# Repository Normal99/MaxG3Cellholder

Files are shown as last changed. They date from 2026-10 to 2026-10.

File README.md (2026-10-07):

# MaxG3Cellholder

Cellholder for a custom 20s4p battery for the Segway Ninebot Max G3 without cutting the divider in the deck compartment.

* **Cells:** 80 × EVE INR21700-40P (Ø21.15 ±0.10 mm, 70.15 ±0.15 mm)
* **Configuration:** 20s4p, 72 V nominal / 84 V full
* **Envelope:** 141 × 270 mm footprint. Holder + cells are **71.8 mm** tall, which leaves ~9 mm of the 81 mm for copper, nickel, fish paper and heat shrink.
* **Placement:** the pack sits in front of the deck divider. The **BMS (ANT 24ZHE6-24S-220A) stands upright on the other side** of the divider, held by a dock that is **part of the top holder half**. Every lead and balance wire leaves the pack at the divider end.
* **Printed parts:** only what's needed. Just the two holder halves. The top one includes the BMS dock. No cover plates, no separate BMS holder.

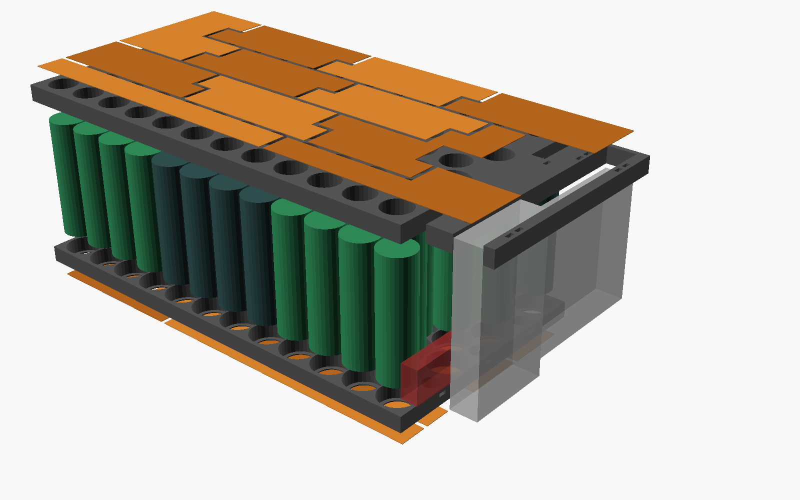
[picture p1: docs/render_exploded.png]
exploded view


---

## 1. What's in the repo

| Path | What it is |
|---|---|
| `stl/holder_bottom.stl`, `stl/holder_top.stl` | Cell holder halves, one piece each. Bottom is 270 mm long; top with BMS dock is 315 mm, so it needs a big bed. |
| `stl/holder_*_a.stl` / `_b.stl` | **The same halves split in two, for normal beds.** Every part fits a 256 × 256 bed (largest: `holder_top_a`, 214 × 141 mm, with the BMS dock). The two parts **lock together through 7 shared cell sockets** (§7). |
| `docs/copper_cutlist.svg` | **Copper cut list:** every distinct copper shape once, 1:1, with count, edge lengths and punch holes |
| `docs/copper_roll_plan.svg` | Every copper piece laid out on a **100 mm wide roll** |
| `docs/copper_top.svg`, `docs/copper_bottom.svg` | 1:1 position of every copper piece on each face, with punch holes, tab flaps and tongue fold lines |
| `docs/wiring_top.svg`, `docs/wiring_bottom.svg` | Wiring diagrams: group numbers, cell polarity, copper pieces and balance taps |
| `docs/layout.md` | Cut list table, plus every group, cell and copper piece |
| `scad/cellholder.scad` | Parametric OpenSCAD model: holder halves with BMS dock, tolerances, BMS size |
| `scad/layout_data.scad` | Generated layout data (do not edit by hand) |
| `generator/layout.py` | Generates the layout, copper pieces, diagrams and templates |

Coordinates used everywhere:

* **x** runs along the 270 mm length. **x = 0 is the divider end of the pack.**
* **y** runs across the 141 mm width. **y = 0 is the side wall the screw post's 80 mm is measured from.**
* **z** is up from the deck floor.

---

## 2. Layout and copper

top wiring
bottom wiring

The footprint fits a staggered grid of 7 rows (12/11/12/11/12/11/12) at 22.2 mm pitch. That makes **81 slots for 80 cells**. The spare slot is left empty at the divider end and doubles as a wire chase (§4).

Almost every 4p group is a compact **2 × 2 diamond**: 2 cells in one row and 2 in the next. The pack is built from bands of them:

| Rows (from the y = 0 side) | Groups | Direction |
|---|---|---|
| Rows 1–2 | **G1 → G5** (G1 = **B−**) | away from the divider |
| Far end | G6 | turn |
| Rows 3–4 | **G7 → G11** | back to the divider |
| Divider end | G12 | turn |
| Rows 5–6 | **G13 → G17** | away from the divider |
| Row 7 | **G18 → G20**, 4 cells in a line (G20 = **B+**) | back to the divider |

### Copper pieces: one straight bar per row

copper cut list

**Each copper piece is a straight bar along each row of cells it covers.**

* Where a piece covers two rows, the two bars are offset by half a cell (that's how the cells are staggered), giving a simple **step shape**.
* Every edge is a straight, square cut.
* **Every cell is fully covered.** Each piece only covers the cells of its own groups, so it is easy to see where it goes.

| Shape | Count | Size | What it is |
|---|---|---|---|
| **A** | **9** | 97.4 × 36 mm step: two 86.3 mm bars, offset 11.1 mm | Standard piece: two diamonds, 8 cells |
| **B** | 2 | same as A with one end squared off at the pack wall | |
| **C** | 2 | 175.5 × 16.7 mm strip | Row 7: 8 cells in a line |
| D–I | 1 each | step shapes | Turn pieces at the two ends of the pack |
| **B−**, **B+** | 1 each | with a **36 × 35 mm lead tongue** | Main leads (§5) |

**How to prepare the copper:**

* **Punch holes:** there's one 8 mm circle over every cell. Punch a hole there, lay the nickel strip over the copper, and weld the nickel to the cell through the hole and to the copper around it. Change `PUNCH_D` in `generator/layout.py` if your punch is a different size. The hole must be smaller than the cell's positive cap.
* **Cells are recessed 0.6 mm:** each cell stops against a thin lip 0.6 mm below the holder face. The copper lies flat on the holder, and the nickel only has to dip about 0.8 mm (lip + copper) through the hole to reach the cell.
* **Roll plan:** `docs/copper_roll_plan.svg` lays out every piece of both faces on a **100 mm wide roll**. One pack uses about **1.1 m of roll** per copper layer.
* **Gaps:** neighbouring pieces have a 2.5 mm gap. The generator checks that no copper ever comes within 10 mm of another group's cell centre.

**Other things to know about the layout:**

* **B− (G1)** and **B+ (G20)** both end at the divider end, on the **top** face.
* Copper pieces:
  * **Top face:** B0 (G1, main −), then B2, B4 … B18, then B20 (G20, main +). That's 11 pieces.
  * **Bottom face:** B1, B3 … B19. That's 10 pieces.
* The balance tap number equals the copper piece number. Taps B0–B20 go to BMS balance pins 0–20 (B0 = B−, B20 = B+).
* **Bands keep voltages low.** Neighbouring copper pieces are at most 12 groups apart (~50 V). Still lay fish paper over each face before wrapping.
* **The last row is the one compromise.** Seven rows can't be split into 2-row bands only. In row 7 the groups G18 → G19 → G20 sit end to end, so current flows lengthwise along the two C strips. **Use double-thickness copper (two layers) for the two C strips.**

To change the layout, edit `GROUP_PATTERN` in `generator/layout.py` and run it again (§10).

---

## 3. Stack-up (height budget 81 mm)

| Layer | mm |
|---|---|
| Fish paper / foam under the pack | your choice |
| Copper + nickel, bottom | ~0.4 |
| Cell recess (thin end-stop lip) | 0.6 |
| Cell (70.15 + 0.15 tolerance + fish-paper ring) | 70.6 |
| Cell recess, top | 0.6 |
| Copper + nickel, top | ~0.4 |
| **Total without wrap** | **~72.6** |

* **Holder halves:** each is 9.6 mm tall, with 9 mm deep sockets. Between the halves the cells are bare, over a 52.6 mm gap.
* **Bore:** Ø21.2 mm, picked with the fit test strip (§7): the cells press in firmly by hand. That leaves a 1.0 mm wall between neighbouring cells. On a different printer, print the test strip again and set `cell_bore` in **both** `scad/cellholder.scad` and `generator/layout.py`.
* **Welding window:** Ø17 mm, the opening in the end stop over every cell.

---

## 4. Deck features

### Divider (20 mm tall, 10 mm wide, full width)

The pack's x = 0 face sits against the divider. Nothing passes under or through the divider, so the 0.5 mm indent under it doesn't matter. Everything that goes to the BMS leaves the pack **above z = 20 mm** at the divider end and goes over the divider:

* **Top balance wires** run over the top face, under the fish paper, to the divider end.
* **Bottom balance wires** run under the bottom face to the **wire chase**: the empty cell slot at the divider end, open top to bottom. The wires rise inside it and leave sideways through the open gap between the holder halves, above the divider.
* **Main leads:** see §5.

### Screw post (80 mm from the side wall, 10 mm tall, just in front of the divider)

The post is on the **BMS side** of the divider (`post_side = "bms"`), so the BMS simply stands just behind it (§8).

* If it turns out to be on the **pack side**, set `post_side = "pack"`. The bottom holder half then gets a Ø12 × 11 mm pocket, and the empty cell slot is placed right over the post.
* If the 80 mm is measured from the **other** side wall, set `POST_FROM_SIDE = 141 - 80` (= 61) in `generator/layout.py`. The whole pattern mirrors automatically.

**Measure before you print:**

* post diameter (assumed Ø10)
* distance from the divider (assumed centre 6 mm)
* which side wall the 80 mm is measured from

---

## 5. Main leads (B−, B+): solder first, then weld

You can't solder to the copper once it's welded: the copper soaks up the heat and cooks the cells. So the leads go onto **tongues that stick out past the end of the pack**, and you solder them on the bench before any cell is touched.

1. Cut the **B−** and **B+** pieces from the cut list **with the tongue**. Each tongue is 36 mm wide and runs **35 mm** past the x = 0 edge (dashed fold line on the template). A doubled tongue (two layers of copper) makes the joint even stronger.
2. **On the bench, with no cells near it:** tin the tongue and solder the lead (10 or 12 AWG silicone) along the outer ~20 mm. A 100 W+ iron or a small torch makes copper easy. Let it cool and slide heat shrink over the joint.
3. Pre-bend the tongue 90° **downwards** at the x = 0 edge.
4. Lay the piece on its cells, add the nickel and weld. The joint hangs down the divider-end face of the top holder half, **above the divider**.
5. **Strain relief:** each tongue folds down through a notch in the BMS dock arm. Zip-tie the lead through the hole pair beside the notch, or through the tie slot in the end wall behind it (y = 32 for B−, y = 109 for B+). That way the lead's weight pulls on the plastic, not on the welds.

**No-solder alternative:** crimp a ring lug on the lead and bolt it to the tongue with M5 or M6 (spring washer + nyloc), outside the pack.

## 6. Balance tabs

There is one tab per copper piece, at the small rectangle on the templates. It sits over plastic between the cells, never over a cell terminal.

1. On each copper piece, cut a **5 × 7 mm U-flap** at the marked spot.
2. **Solder the balance wire (22–24 AWG silicone) to the flap on the bench**, before welding. Then weld the piece. Solder the B0 and B20 balance wires to the main-lead tongues in the same bench step.
3. Run the wires to the divider end:
   * **Top face:** lay the wires flat on the top face.
   * **Bottom face:** lay them flat on the bottom face and route them up through the wire chase.
4. Fix them with kapton tape, then cover each face with fish paper.
5. Put a fuse or PTC on each balance lead at the connector end if your BMS harness doesn't already have them.

---

## 7. Printing

### What to print

It's only the two holder halves. The BMS dock is part of the top half.

| Your bed | Print these |
|---|---|
| **≥ 315 × 141 mm** | `holder_bottom.stl` + `holder_top.stl` (one piece each) |
| **Smaller, e.g. 256 × 256 mm** (Bambu, Prusa, Ender …) | the four split parts below |

The split parts are all 9.6 mm tall:

| File | Size (mm) |
|---|---|
| `stl/holder_bottom_a.stl` | 146 × 141 |
| `stl/holder_bottom_b.stl` | 157 × 141 |
| `stl/holder_top_b.stl` | 135 × 141 |
| `stl/holder_top_a.stl` (has the BMS dock) | 214 × 141 |

### Print order

0. **`stl/bore_test.stl` first: the cell fit test** (137 × 35 mm, ~15 cm³, about half an hour).
   * It's a row of 6 cell holes, **21.1 to 21.6 mm**, built exactly like the holder: same lip, depth, spacing and circle resolution. Each hole has its size printed on the tab next to it.
   * Push a cell into each hole and pick the one where it goes in **firmly by hand and doesn't fall out** when you turn the strip over.
   * Set that number as `cell_bore` in `scad/cellholder.scad` **and** `BORE_D` in `generator/layout.py`, then re-run `python3 generator/layout.py` and `sh scad/export.sh`. (Or just tell Claude the number.)

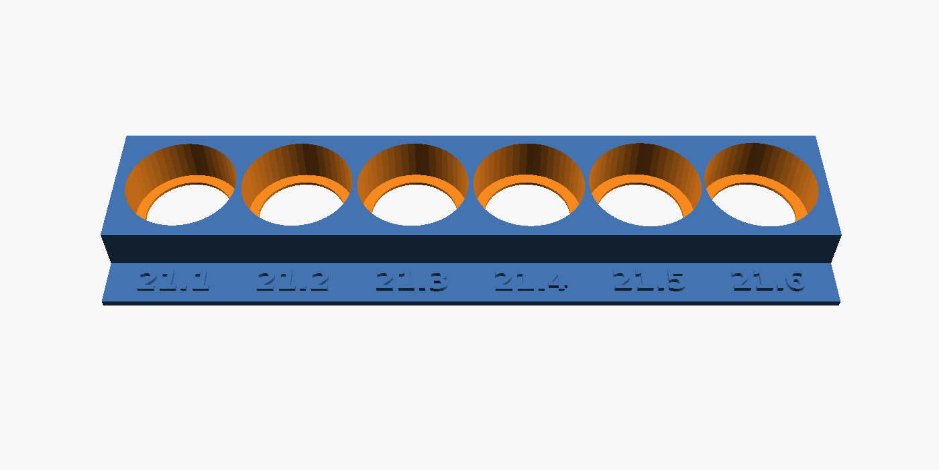
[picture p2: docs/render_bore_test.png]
fit test strip
   
1. `holder_bottom_a`. Check a few cells in it before printing the rest.
2. `holder_bottom_b`. It locks to `_a` through the key cells (see below).
3. `holder_top_b`.
4. **`holder_top_a` last.** It places the BMS slot, so check these first (§4, §8):
   * the screw-post position
   * at least ~91 mm of height past the divider

### Settings

* **Material: PETG, ASA or ABS. Not PLA** (it creeps and softens in a hot deck).
* 0.2 mm layers (the 0.6 mm lip under each cell is then exactly 3 layers), 3 walls, 15–25 % infill.
* **Orientation:** as exported, flat face down. **No supports** for any part. The BMS dock is a flat arm in the same layer as the top half, with only vertical holes.
* **Split parts:** they join mechanically, so no glue or pins are needed (see below).

### How the split parts lock together

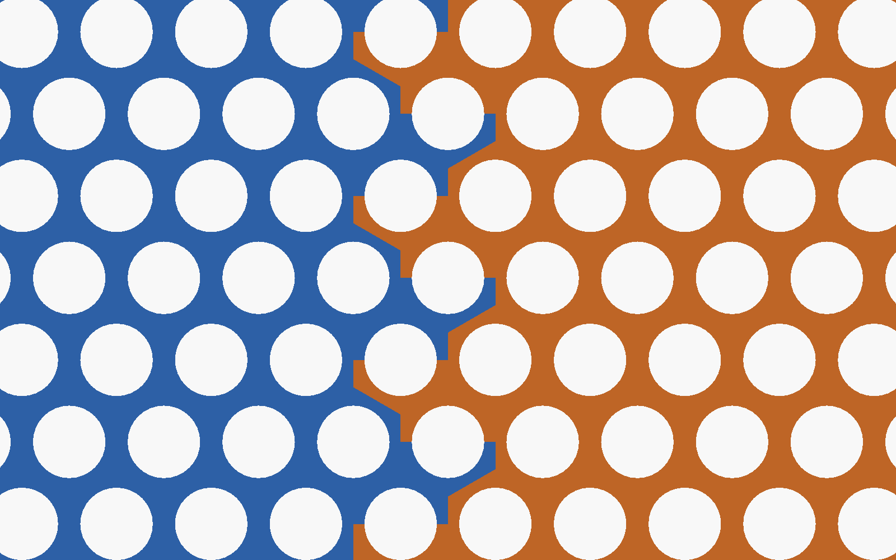
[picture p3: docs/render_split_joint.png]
split joint


The seam doesn't run between cells. It runs **through a column of cells**, one **key cell** per row (7 per half). In the bottom half they're at x ≈ 124 / 135 mm, in the top half one column further, at x ≈ 146 / 157 mm.

* **How a key cell is split:** its socket is cut in half across the centre. One half belongs to part `_a`, the other to `_b`.
* **Alternating halves:** row by row, `_a` gets the upper half, then the lower half, and so on.
* **Why it locks:** once a key cell is pushed in, it sits in a half-socket of **both** parts. Each key cell acts as a 21 mm dowel, and because the halves alternate, the parts can't slide apart in any direction across the pack.
* **Assembly:** lay `_a` and `_b` side by side on the table, close the seam, and **push the 7 key cells in first**. After that, fill the rest.
* **Offset seams:** the top and bottom seams are a column apart, so they never line up. Each seam is backed by a solid stretch of the other half, like staggered joints in brickwork, and the pack has no weak line to fold along.
* **Extra security:** a drop of CA glue along the seam keeps the parts together while you handle them without cells. The welded copper and nickel, which bridge the seam on both faces, make the joint permanent.

## 8. BMS dock (built into the top holder half)

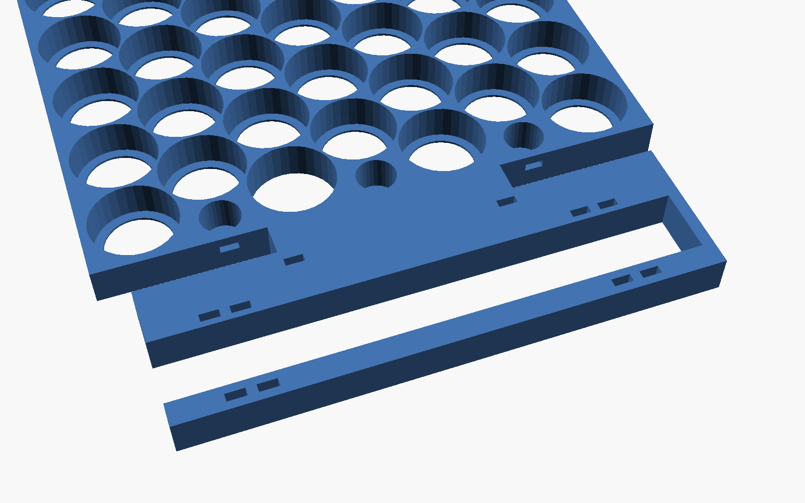
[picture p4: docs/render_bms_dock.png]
BMS dock


The ANT BMS (125 × 90 × 16 mm) **stands upright on its long edge** on the deck floor, parallel to the divider, just behind the screw post. The **top holder half** has a flat arm that reaches over the divider (it sits at 62–72 mm height, the divider is only 20 mm tall) with a **slot the BMS drops into**. It only takes about **45 mm of deck length** past the divider, and there is no separate part to print or fix down.

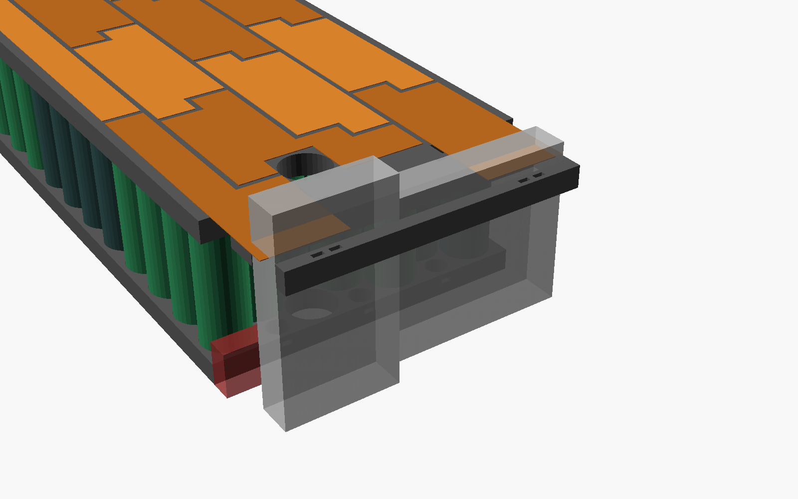
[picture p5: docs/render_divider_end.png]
divider end


* **Height:** the BMS is 90 mm tall standing, so make sure the space past the divider has at least ~91 mm.
* **Connector end** (wide 90 mm head): the slot is **open** there, so the balance connectors stay free.
* **Narrow end** (70 mm section with the power leads): a cross bar closes the slot. That section sits 10 mm off the floor, so the lower leads have room to bend outwards.
* **Hold-down:** two zip ties, one near each end, through the hole pairs in both rails and over the BMS's top edge.
* **Lead notches:** the arm has notches at the pack end, so the **B− / B+ tongues still fold down** over the end of the pack. A hole pair beside each notch takes a zip tie around the lead (strain relief).
* **Printing:** the arm is the same 9.6 mm slab as the half, so it prints flat with it.

Settings in `scad/cellholder.scad`:

* `bms_head_at`: which side of the deck the connector end faces (`"y0"` or `"y1"`)
* `bms_y`: where the BMS sits across the deck
* `bms_*` sizes, if you change BMS
* `bms_dock = false` removes the dock

Then run `sh scad/export.sh`.

## 9. Assembly order

1. Insert the cells into the **bottom** half, following `docs/wiring_bottom.svg`. With the split parts, put the 7 key cells in first to lock `_a` and `_b` together (§7). Then fit the **top** half the same way.
   * **Top** terminals: G1 is **−** up, G2 is **+** up, and so on, alternating.
   * Before you weld anything, check every cell's polarity against the diagrams with a meter.
2. Fit fish-paper rings on the positive ends.
3. **Bottom face:**
   * Pre-solder the balance wires to the flaps of B1 … B19.
   * Lay the punched copper pieces (see `docs/copper_bottom.svg`; it's drawn as seen from below).
   * Weld the nickel through the holes.
   * Tape the wires and route them into the chase.
4. **Top face:**
   * Pre-solder the B− and B+ leads and the B2 … B18 balance wires.
   * Lay the copper, weld the nickel, fold the tongues down and zip-tie the leads.
5. Measure each tap against B0 before plugging into the BMS. Each step should be ~3.6–4.2 V.
6. Fish paper over both faces, then wrap the pack (foam + heat shrink). Make sure the controller is rated for **84 V** before connecting.

---

## 10. Regenerating / customising

```sh
pip install shapely                 # one time
python3 generator/layout.py         # layout -> scad/layout_data.scad + docs/*.svg + docs/layout.md
sh scad/export.sh                   # all STLs into stl/ (OpenSCAD 2021.01+)
openscad scad/cellholder.scad       # preview, set part = "assembly" / "exploded"
```

Parameters live in two places:

* **`generator/layout.py`:**
  * envelope (`PACK_L`, `PACK_W`) and `PITCH`
  * the screw post (`POST_FROM_SIDE`, `POST_FROM_DIVIDER`, `POST_D`, `POST_H`)
  * copper gap, punch hole size (`PUNCH_D`), lead tongue size (`LEAD_W`, `LEAD_LEN`) and roll width (`ROLL_W`)
  * the group pattern (`GROUP_PATTERN`)
* **`scad/cellholder.scad`:**
  * cell size and bore, welding window, cell recess, socket depth, tie slots
  * screw post side (`post_side`)
  * BMS size and dock settings

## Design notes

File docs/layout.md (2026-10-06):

# Generated layout

Generated by `generator/layout.py`. Coordinates in mm, x = 0 at the divider, y = 0 at the side wall the screw post is measured from.

## Copper cut list

Every copper edge is a straight line. Identical letters = identical pieces (a mirrored copy is the same template flipped over).

| Shape | Count | Pieces |
|---|---|---|
| A | 9 | top B2, top B4, top B8, top B10, top B14, bottom B3, bottom B9, bottom B13, bottom B15 |
| B | 2 | top B16, bottom B1 |
| C | 2 | top B18, bottom B19 |
| D | 1 | top B6 |
| E | 1 | top B12 |
| F | 1 | bottom B5 |
| G | 1 | bottom B7 |
| H | 1 | bottom B11 |
| I | 1 | bottom B17 |
| B- | 1 | top B0 + 36 x 35 mm lead tongue |
| B+ | 1 | top B20 + 36 x 35 mm lead tongue |

All pieces fit across a 100 mm copper roll; one pack uses about 1091 mm of roll per copper layer (see copper_roll_plan.svg).

Largest voltage step between neighbouring copper pieces on one face: 12 groups (~50 V at full charge).

## Series groups

| Group | Top terminal | Cells (x, y) | Contacts to next group |
|---|---|---|---|
| G1 | - | (13, 13), (24, 32), (35, 13), (46, 32) | 3 |
| G2 | + | (57, 13), (68, 32), (80, 13), (91, 32) | 3 |
| G3 | - | (102, 13), (113, 32), (124, 13), (135, 32) | 3 |
| G4 | + | (146, 13), (157, 32), (168, 13), (179, 32) | 3 |
| G5 | - | (190, 13), (202, 32), (213, 13), (224, 32) | 3 |
| G6 | + | (235, 13), (246, 32), (257, 13), (257, 51) | 3 |
| G7 | - | (213, 51), (224, 70), (235, 51), (246, 70) | 3 |
| G8 | + | (168, 51), (179, 70), (190, 51), (202, 70) | 3 |
| G9 | - | (124, 51), (135, 70), (146, 51), (157, 70) | 3 |
| G10 | + | (80, 51), (91, 70), (102, 51), (113, 70) | 3 |
| G11 | - | (35, 51), (46, 70), (57, 51), (68, 70) | 4 |
| G12 | + | (13, 51), (24, 70), (24, 109), (35, 90) | 3 |
| G13 | - | (46, 109), (57, 90), (68, 109), (80, 90) | 3 |
| G14 | + | (91, 109), (102, 90), (113, 109), (124, 90) | 3 |
| G15 | - | (135, 109), (146, 90), (157, 109), (168, 90) | 3 |
| G16 | + | (179, 109), (190, 90), (202, 109), (213, 90) | 3 |
| G17 | - | (224, 109), (235, 90), (246, 109), (257, 90) | 4 |
| G18 | + | (190, 128), (213, 128), (235, 128), (257, 128) | 1 |
| G19 | - | (102, 128), (124, 128), (146, 128), (168, 128) | 1 |
| G20 | + | (13, 128), (35, 128), (57, 128), (80, 128) | - |

## Copper pieces

| Face | Tap | Shape | Joins | Tab / lead position (x, y) |
|---|---|---|---|---|
| top | B0 | B- | G1 | lead tongue 36 mm wide at y = 22.4 |
| top | B2 | A | G2 + G3 | (68.4, 19.2) |
| top | B4 | A | G4 + G5 | (157.2, 19.2) |
| top | B6 | D | G6 + G7 | (223.8, 57.7) |
| top | B8 | A | G8 + G9 | (135.0, 57.7) |
| top | B10 | A | G10 + G11 | (46.2, 57.7) |
| top | B12 | E | G12 + G13 | (35.1, 102.5) |
| top | B14 | A | G14 + G15 | (101.7, 102.5) |
| top | B16 | B | G16 + G17 | (190.5, 102.5) |
| top | B18 | C | G18 + G19 | (112.8, 128.2) |
| top | B20 | B+ | G20 | lead tongue 36 mm wide at y = 118.6 |
| bottom | B1 | B | G1 + G2 | (35.1, 32.0) |
| bottom | B3 | A | G3 + G4 | (112.8, 19.2) |
| bottom | B5 | F | G5 + G6 | (201.6, 19.2) |
| bottom | B7 | G | G7 + G8 | (179.4, 57.7) |
| bottom | B9 | A | G9 + G10 | (90.6, 57.7) |
| bottom | B11 | H | G11 + G12 | (35.1, 76.9) |
| bottom | B13 | A | G13 + G14 | (57.3, 102.5) |
| bottom | B15 | A | G15 + G16 | (146.1, 102.5) |
| bottom | B17 | I | G17 + G18 | (201.6, 128.2) |
| bottom | B19 | C | G19 + G20 | (24.0, 128.2) |

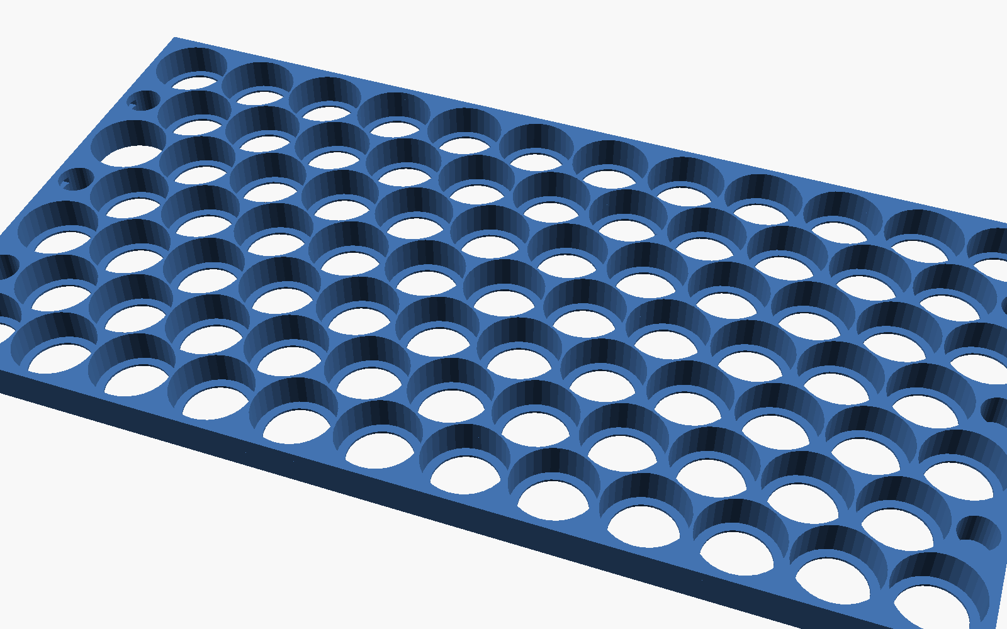
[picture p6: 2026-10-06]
docs/render_holder_bottom.png

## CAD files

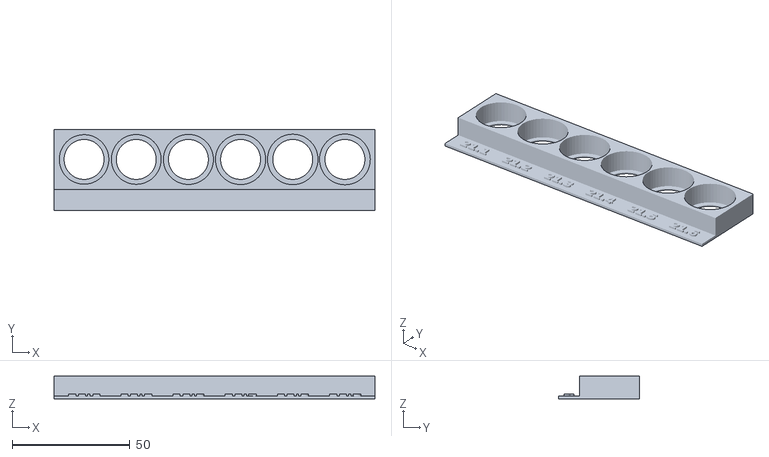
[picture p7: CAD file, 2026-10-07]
stl/bore_test.stl
136.6 x 34.6 x 9.60

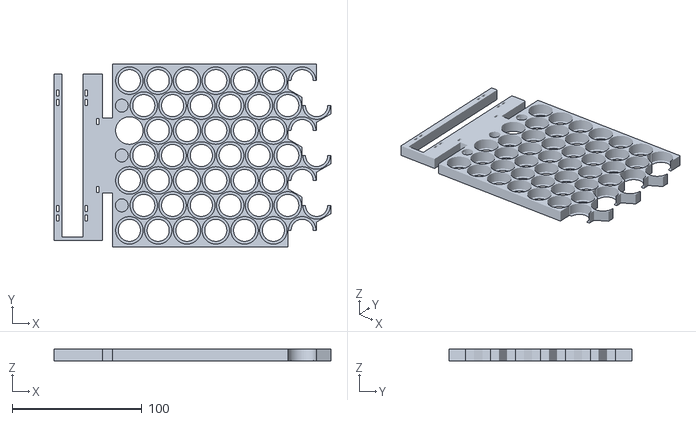
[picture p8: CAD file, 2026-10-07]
stl/holder_top_a.stl
213.5 x 141.0 x 9.60

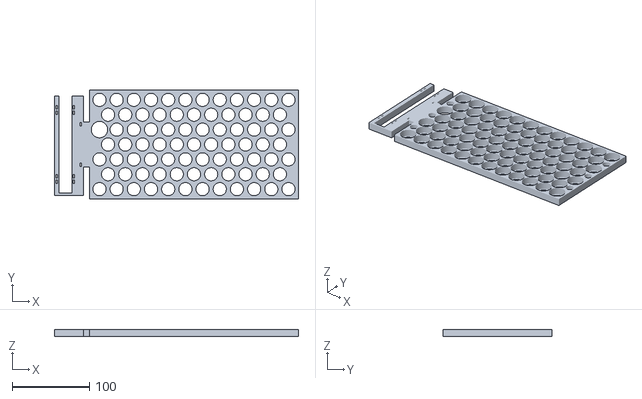
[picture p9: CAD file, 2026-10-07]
stl/holder_top.stl
315.2 x 141.0 x 9.60

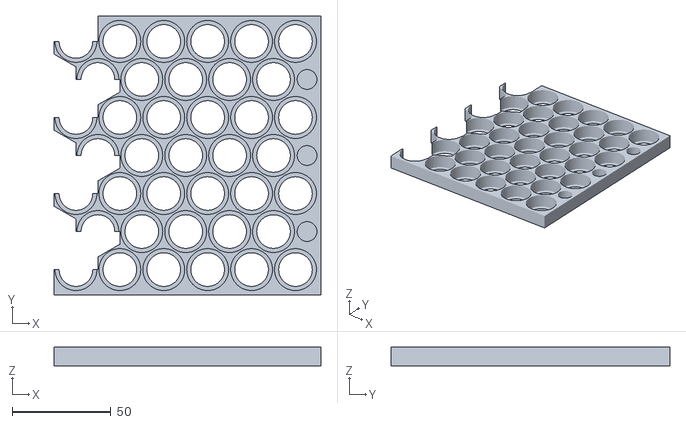
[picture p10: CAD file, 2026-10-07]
stl/holder_top_b.stl
135.0 x 141.0 x 9.60

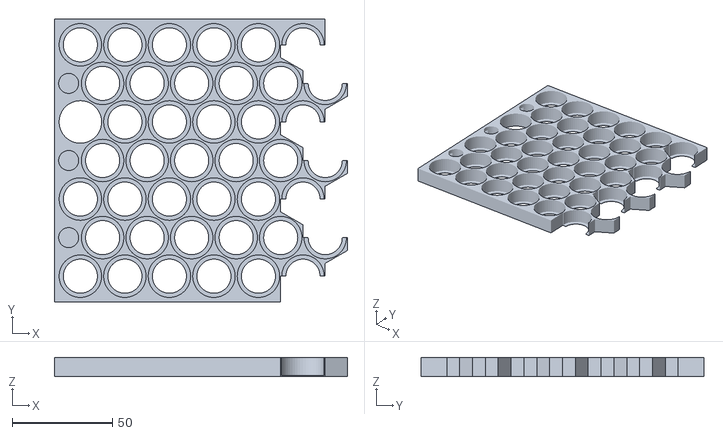
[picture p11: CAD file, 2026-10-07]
stl/holder_bottom_a.stl
146.1 x 141.0 x 9.60

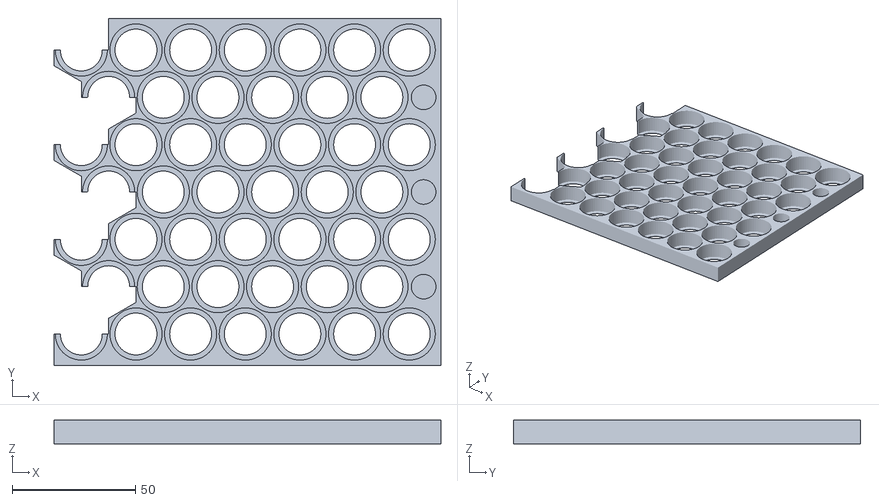
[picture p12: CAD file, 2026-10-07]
stl/holder_bottom_b.stl
157.2 x 141.0 x 9.60

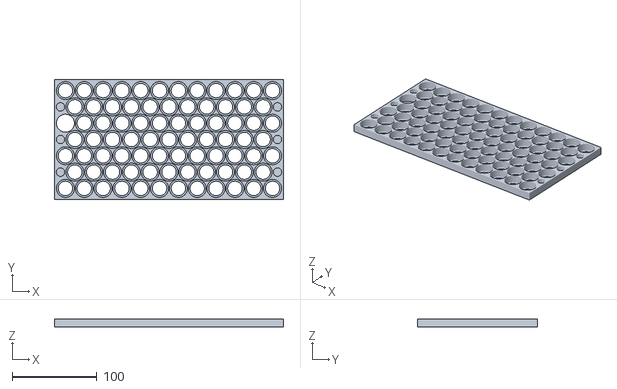
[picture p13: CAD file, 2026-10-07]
stl/holder_bottom.stl
270.0 x 141.0 x 9.60

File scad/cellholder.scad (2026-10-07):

// =====================================================================
//  Segway Ninebot Max G3 - 20s4p 21700 cell holder (EVE 40P) + BMS dock
//  Pack envelope 141 x 270 x 81 mm, fits in front of the deck divider,
//  the BMS stands upright on the other side of the divider, held by an
//  arm that is part of the TOP holder half and reaches over the divider.
//
//  Cell layout and copper pieces come from layout_data.scad, generated by
//  ../generator/layout.py.
//
//  Coordinates: x = 270 mm length, x = 0 is the DIVIDER end of the pack
//               (the divider is x = -div_w .. 0, the BMS is at x < -div_w)
//               y = 141 mm width,  y = 0 is the side wall the screw post
//                                   is measured from (80 mm)
//               z = height,         z = 0 is the deck floor
//
//  Parts (set `part`, or run export.sh):
//    holder_bottom, holder_top             cell holder halves (the top one carries the BMS dock)
//    holder_bottom_a/_b, holder_top_a/_b   same, split for beds < 270 mm
//    assembly                              everything in place (preview only)
// =====================================================================
include <layout_data.scad>

part = "assembly";

/* [Cell] */
cell_d      = 21.15;  // EVE 40P datasheet: 21.15 +-0.10
cell_len    = 70.6;   // 70.15 +0.15 max + fish-paper ring + margin
cell_bore   = 21.2;   // socket bore, picked with the fit test strip (1.0 mm web at 22.2 pitch). Also in layout.py
window_d    = 17.0;   // opening in the end stop over every cell. Also in layout.py

/* [Holder] */
cell_recess = 0.6;    // cells sit this far below the holder face (= end-stop lip, 3 layers)
sock        = 9.0;    // socket depth per half
void_d      = 10.0;   // lightening pocket in the empty end spots of the short rows
tie_w       = 4.6;    // zip-tie slot through the end wall (fits 3.6 mm ties)
tie_h       = 2.0;

/* [Screw post] */
post_clear  = 1.0;    // radial clearance
post_extra  = 1.0;    // height clearance

/* [Deck] */
div_w       = 10.0;   // divider width (x)
div_h       = 20.0;   // divider height
post_side   = "bms";  // "bms": post is on the BMS side of the divider, "pack": on the cell side

/* [BMS dock - ANT BMS 24ZHE6-24S-220A, built into the TOP holder half] */
bms_dock    = true;
bms_l       = 125;    // BMS length
bms_w       = 90;     // BMS width at the connector (head) end = height when standing
bms_body_w  = 70;     // width of the narrow section the power leads come out of
bms_head_l  = 50;     // length of the wide head section (balance connectors on its end)
bms_t       = 16;     // BMS thickness
bms_y       = 70.5;   // centre of the BMS across the deck (y)
bms_head_at = "y1";   // which deck side the connector end faces: "y0" or "y1"
bms_slot    = 0.4;    // clearance in the slot (thickness and length)
dock_rail   = 6;      // width of the outer rail of the slot
dock_end    = 3;      // cross bar that closes the slot at the narrow end
lead_notch  = 8;      // notches at the pack end the B-/B+ tongues fold down through

/* [Fit test strip] */
test_bores  = [21.1, 21.2, 21.3, 21.4, 21.5, 21.6];   // hole sizes to try

/* [Quality] */
$fn = 48;

// ---------------------------------------------------------------------
L = pack_l;
W = pack_w;
half_h   = cell_recess + sock;
total_h  = cell_len + 2 * cell_recess;
gap_h    = cell_len - 2 * sock;
post_d   = post[2];
post_h   = post[3];
// screw post position: measured from the divider face on its own side
post_xy  = post_side == "pack" ? [post[0], post[1]] : [-div_w - post[0], post[1]];
tie_z    = half_h - 2.5 - tie_h;   // tie slot (local z)
// BMS dock: the BMS stands on the floor just behind the screw post
bms_xn   = post_side == "bms" ? post_xy[0] - post_d / 2 - post_clear - 1 : -div_w - 1;   // near face
bms_xf   = bms_xn - bms_t;                                                              // far face
bms_y0   = bms_y - bms_l / 2;
bms_y1   = bms_y + bms_l / 2;
narrow_y1 = bms_head_at == "y0";   // the narrow end (closed by the cross bar) is at y1
echo(str("PACK HEIGHT = ", total_h, " mm + copper/nickel/insulation (limit 81)  gap between halves = ", gap_h));
assert(total_h <= 78, "pack too tall for 81 mm with copper and insulation");

// ---------------------------------------------------------------------
// 2D helpers
// ---------------------------------------------------------------------
module outline() { square([L, W]); }

module split_mask(which, face = "bottom") {
    // which: "all", "a", "b"   (zig-zag split between cells)
    // (the BMS dock at x < 0 belongs to part "a")
    sa = face == "top" ? split_a_top : split_a;   // the two halves split at different columns
    if (which == "a") union() { polygon(sa); translate([-200, -1]) square([200.01, W + 2]); }
    else if (which == "b") difference() { translate([0, -1]) square([L + 1, W + 2]); polygon(sa); }
    else translate([-200, -1]) square([L + 201, W + 2]);
}

module bores()   { for (c = cells) translate([c[0], c[1]]) circle(d = cell_bore); }
module windows() { for (c = cells) translate([c[0], c[1]]) circle(d = window_d); }
module chase2d() { translate(chase) circle(d = cell_bore); }
module post2d()  {   // open towards the divider end so it never grazes the wall
    hull() for (dx = [0, -post_xy[0] - 1]) translate(post_xy + [dx, 0]) circle(d = post_d + 2 * post_clear);
}
module voids()   { for (v = concat(voids_x0, voids_x1)) translate(v) circle(d = void_d); }
function in_notch(y) = len([for (l = leads) if (abs(y - l[0]) < l[2] / 2) 1]) > 0;
module tie_slots(face) {
    // lead strain-relief slots through the end wall; on the top half with
    // the dock only those that open into a lead notch stay
    for (v = voids_x0) if (!(face == "top" && bms_dock) || in_notch(v[1]))
        translate([-1, v[1] - tie_w / 2]) square([v[0], tie_w]);
}

// BMS dock outline (world xy, x < 0): solid bridge over the divider up to
// the slot, outer rail beyond it, cross bar at the narrow end, notches for
// the lead tongues, zip-tie hole pairs for the BMS straps and the leads.
module dock2d() {
    s  = bms_slot / 2;
    yl = narrow_y1 ? bms_y0 - s : bms_y0 - s - dock_end;
    yh = narrow_y1 ? bms_y1 + s + dock_end : bms_y1 + s;
    xr = bms_xf - s - dock_rail;                  // outer edge of the rail
    module pair(x, y, along_x = false) {          // two tie holes 7 mm apart
        for (d = [-3.5, 3.5])
            translate(along_x ? [x + d, y] : [x, y + d])
                square(along_x ? [tie_h, tie_w] : [tie_h, tie_w], center = true);
    }
    difference() {
        union() {
            translate([bms_xn + s, yl]) square([-bms_xn - s + 0.01, yh - yl]);   // bridge
            translate([xr, yl]) square([dock_rail, yh - yl]);                    // outer rail
            translate([xr, narrow_y1 ? bms_y1 + s : yl]) square([bms_xn + s - xr, dock_end]);
        }
        for (l = leads) translate([-lead_notch, l[0] - l[2] / 2 - 1]) square([lead_notch + 1, l[2] + 2]);
        // BMS straps: hole pairs in both rails near each end of the BMS
        for (y = [bms_y0 + 18, bms_y1 - 18]) {
            pair(bms_xn + s + 2.5, y);
            pair(xr + dock_rail / 2, y);
        }
        // lead straps: hole pair beside each notch
        for (l = leads) for (d = [-1, 1])
            translate([-lead_notch - 3.5, l[0] + d * (l[2] / 2 + 4)]) square([tie_h, tie_w], center = true);
    }
}

// 3D slab: linear_extrude a 2D region between z0 and z1
module slab(z0, z1) { translate([0, 0, z0]) linear_extrude(z1 - z0) children(); }

// ---------------------------------------------------------------------
// Holder half. Local coords: z = 0 is the outer face (copper side),
// xy = world xy. Print in this orientation (face down, no supports).
// The cells stop against a thin lip, cell_recess below the face, so the
// punched copper + nickel only has to dip cell_recess to reach the cell.
// ---------------------------------------------------------------------
module holder_half(face = "bottom", which = "all") {
    zs = cell_recess;             // sockets start
    zt = half_h;                  // inner end
    pocket = face == "bottom" && post_side == "pack";
    zp = pocket ? min(zt, post_h + post_extra) : -1;

    module socket_layer(cut_post, cut_tie) {
        intersection() {
            split_mask(which, face);
            difference() {
                outline();
                bores();
                chase2d();
                voids();
                if (cut_post) post2d();
                if (cut_tie) tie_slots(face);
            }
        }
    }
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

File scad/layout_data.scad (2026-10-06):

// GENERATED by generator/layout.py - do not edit by hand

pack_l = 270.0;
pack_w = 141.0;
pitch = 22.2;
// [x, y, group(1-based), up-terminal]
cells = [[12.900,12.823,1,"-"],[35.100,12.823,1,"-"],[57.300,12.823,2,"+"],[79.500,12.823,2,"+"],[101.700,12.823,3,"-"],[123.900,12.823,3,"-"],[146.100,12.823,4,"+"],[168.300,12.823,4,"+"],[190.500,12.823,5,"-"],[212.700,12.823,5,"-"],[234.900,12.823,6,"+"],[257.100,12.823,6,"+"],[24.000,32.048,1,"-"],[46.200,32.048,1,"-"],[68.400,32.048,2,"+"],[90.600,32.048,2,"+"],[112.800,32.048,3,"-"],[135.000,32.048,3,"-"],[157.200,32.048,4,"+"],[179.400,32.048,4,"+"],[201.600,32.048,5,"-"],[223.800,32.048,5,"-"],[246.000,32.048,6,"+"],[12.900,51.274,12,"+"],[35.100,51.274,11,"-"],[57.300,51.274,11,"-"],[79.500,51.274,10,"+"],[101.700,51.274,10,"+"],[123.900,51.274,9,"-"],[146.100,51.274,9,"-"],[168.300,51.274,8,"+"],[190.500,51.274,8,"+"],[212.700,51.274,7,"-"],[234.900,51.274,7,"-"],[257.100,51.274,6,"+"],[24.000,70.500,12,"+"],[46.200,70.500,11,"-"],[68.400,70.500,11,"-"],[90.600,70.500,10,"+"],[112.800,70.500,10,"+"],[135.000,70.500,9,"-"],[157.200,70.500,9,"-"],[179.400,70.500,8,"+"],[201.600,70.500,8,"+"],[223.800,70.500,7,"-"],[246.000,70.500,7,"-"],[35.100,89.726,12,"+"],[57.300,89.726,13,"-"],[79.500,89.726,13,"-"],[101.700,89.726,14,"+"],[123.900,89.726,14,"+"],[146.100,89.726,15,"-"],[168.300,89.726,15,"-"],[190.500,89.726,16,"+"],[212.700,89.726,16,"+"],[234.900,89.726,17,"-"],[257.100,89.726,17,"-"],[24.000,108.952,12,"+"],[46.200,108.952,13,"-"],[68.400,108.952,13,"-"],[90.600,108.952,14,"+"],[112.800,108.952,14,"+"],[135.000,108.952,15,"-"],[157.200,108.952,15,"-"],[179.400,108.952,16,"+"],[201.600,108.952,16,"+"],[223.800,108.952,17,"-"],[246.000,108.952,17,"-"],[12.900,128.177,20,"+"],[35.100,128.177,20,"+"],[57.300,128.177,20,"+"],[79.500,128.177,20,"+"],[101.700,128.177,19,"-"],[123.900,128.177,19,"-"],[146.100,128.177,19,"-"],[168.300,128.177,19,"-"],[190.500,128.177,18,"+"],[212.700,128.177,18,"+"],[234.900,128.177,18,"+"],[257.100,128.177,18,"+"]];
chase = [12.900,89.726];
post = [6.000,80.000,10.000,10.000];
// [y, name, width]  main lead tongues leave over the divider end (x = 0)
leads = [[22.436,"B-",35.952],[118.564,"B+",35.952]];
voids_x0 = [[7.050,32.048],[7.050,70.500],[7.050,108.952]];
voids_x1 = [[262.950,32.048],[262.950,70.500],[262.950,108.952]];
split_a = [[0.000,141.000],[135.000,141.000],[135.000,128.177],[112.800,128.177],[112.800,121.769],[123.900,115.360],[123.900,108.952],[146.100,108.952],[146.100,102.543],[135.000,96.134],[135.000,89.726],[112.800,89.726],[112.800,83.317],[123.900,76.909],[123.900,70.500],[146.100,70.500],[146.100,64.091],[135.000,57.683],[135.000,51.274],[112.800,51.274],[112.800,44.866],[123.900,38.457],[123.900,32.048],[146.100,32.048],[146.100,25.640],[135.000,19.231],[135.000,12.823],[112.800,12.823],[112.800,0.000],[0.000,0.000]];          // bottom half
split_a_top = [[0.000,141.000],[157.200,141.000],[157.200,128.177],[135.000,128.177],[135.000,121.769],[146.100,115.360],[146.100,108.952],[168.300,108.952],[168.300,102.543],[157.200,96.134],[157.200,89.726],[135.000,89.726],[135.000,83.317],[146.100,76.909],[146.100,70.500],[168.300,70.500],[168.300,64.091],[157.200,57.683],[157.200,51.274],[135.000,51.274],[135.000,44.866],[146.100,38.457],[146.100,32.048],[168.300,32.048],[168.300,25.640],[157.200,19.231],[157.200,12.823],[135.000,12.823],[135.000,0.000],[0.000,0.000]];  // top half
// key cells of the print splits (socket shared by both parts)
split_keys = [[123.900,12.823],[135.000,32.048],[123.900,51.274],[135.000,70.500],[123.900,89.726],[135.000,108.952],[123.900,128.177]];
split_keys_top = [[146.100,12.823],[157.200,32.048],[146.100,51.274],[157.200,70.500],[146.100,89.726],[157.200,108.952],[146.100,128.177]];
top_copper = [[[3.100,4.460],[-35.000,4.460],[-35.000,40.411],[2.600,40.411],[3.100,40.411],[56.050,40.411],[56.050,23.686],[44.950,23.686],[44.950,4.460],[3.100,4.460]],[[58.550,21.186],[58.550,40.411],[144.850,40.411],[144.850,23.686],[133.750,23.686],[133.750,4.460],[47.450,4.460],[47.450,21.186]],[[147.350,21.186],[147.350,40.411],[233.650,40.411],[233.650,23.686],[222.550,23.686],[222.550,4.460],[136.250,4.460],[136.250,21.186]],[[236.150,21.186],[236.150,42.911],[202.850,42.911],[202.850,59.637],[213.950,59.637],[213.950,78.863],[267.400,78.863],[267.400,4.460],[225.050,4.460],[225.050,21.186]],[[125.150,59.637],[125.150,78.863],[211.450,78.863],[211.450,62.137],[200.350,62.137],[200.350,42.911],[114.050,42.911],[114.050,59.637]],[[36.350,59.637],[36.350,78.863],[122.650,78.863],[122.650,62.137],[111.550,62.137],[111.550,42.911],[25.250,42.911],[25.250,59.637]],[[2.600,78.863],[25.250,78.863],[25.250,100.589],[14.150,100.589],[14.150,117.314],[78.250,117.314],[78.250,98.089],[89.350,98.089],[89.350,81.363],[33.850,81.363],[33.850,62.137],[22.750,62.137],[22.750,42.911],[2.600,42.911]],[[178.150,98.089],[178.150,81.363],[91.850,81.363],[91.850,100.589],[80.750,100.589],[80.750,117.314],[167.050,117.314],[167.050,98.089]],[[267.400,81.363],[180.650,81.363],[180.650,100.589],[169.550,100.589],[169.550,117.314],[267.400,117.314]],[[267.400,136.540],[267.400,119.814],[91.850,119.814],[91.850,136.540]],[[3.100,136.540],[89.350,136.540],[89.350,119.814],[11.650,119.814],[11.650,100.589],[2.600,100.589],[2.600,100.589],[-35.000,100.589],[-35.000,136.540],[2.600,136.540]]];
bottom_copper = [[[89.350,4.460],[2.600,4.460],[2.600,40.411],[100.450,40.411],[100.450,23.686],[89.350,23.686]],[[102.950,21.186],[102.950,40.411],[189.250,40.411],[189.250,23.686],[178.150,23.686],[178.150,4.460],[91.850,4.460],[91.850,21.186]],[[191.750,21.186],[191.750,40.411],[247.250,40.411],[247.250,59.637],[267.400,59.637],[267.400,4.460],[180.650,4.460],[180.650,21.186]],[[169.550,59.637],[169.550,78.863],[267.400,78.863],[267.400,62.137],[244.750,62.137],[244.750,42.911],[158.450,42.911],[158.450,59.637]],[[80.750,59.637],[80.750,78.863],[167.050,78.863],[167.050,62.137],[155.950,62.137],[155.950,42.911],[69.650,42.911],[69.650,59.637]],[[2.600,78.863],[25.250,78.863],[25.250,100.589],[2.600,100.589],[2.600,117.314],[33.850,117.314],[33.850,98.089],[44.950,98.089],[44.950,78.863],[78.250,78.863],[78.250,62.137],[67.150,62.137],[67.150,42.911],[2.600,42.911]],[[133.750,98.089],[133.750,81.363],[47.450,81.363],[47.450,100.589],[36.350,100.589],[36.350,117.314],[122.650,117.314],[122.650,98.089]],[[222.550,98.089],[222.550,81.363],[136.250,81.363],[136.250,100.589],[125.150,100.589],[125.150,117.314],[211.450,117.314],[211.450,98.089]],[[213.950,100.589],[213.950,119.814],[180.650,119.814],[180.650,136.540],[267.400,136.540],[267.400,81.363],[225.050,81.363],[225.050,100.589]],[[178.150,136.540],[178.150,119.814],[2.600,119.814],[2.600,136.540]]];

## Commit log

2026-10-06 Add 20s4p EVE 40P cell holder for Segway Max G3 deck
    - Parametric OpenSCAD model: holder halves, insulating cover plates with
    balance-tab slots, wire grooves, B-/B+ lead notches, zip-tie anchors,
    screw-post pocket and wire chase; split variants for beds < 270 mm
    - Layout generator: regular U-shaped 20s4p pattern (identical zig-zag
    groups in lane A, repeating pattern in lane B), B-/B+ at divider end
    - Wiring diagrams, 1:1 copper cutting templates, layout table
    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
    [cellholder.scad, holder_bottom.stl, holder_bottom_a.stl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]
2026-10-06 Rectangular copper busbars, bigger lead tongues, 100 mm roll plan
    - New 20s4p layout: bands of 2x2 diamond groups; every copper piece is a
    rectangle (12 identical 80.9 x 36 mm) or an L of two rectangles
    - B-/B+ tongues widened to 36 mm and extended 35 mm past the divider end;
    rim and cover notches follow the tongue width
    - Balance tab slots square to the pieces, checked for window clearance
    - Copper cut list (one 1:1 template per shape) and a cutting plan for a
    100 mm wide copper roll
    - Regenerated STLs, wiring diagrams and README
    Claude-Session: https://claude.ai/code/session_01NDVQLejGTm6eSJXc2tJ3NB
    [cellholder.scad, holder_top.stl, holder_top_a.stl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]
2026-10-06 Drop cover plates, recess cells 0.6 mm, row-bar copper with punch holes, BMS cradle
    - Remove both cover plates and the rim/peg features that served them
    - Cells now stop 0.6 mm below the holder face (thin end-stop lip) so
    punched copper + nickel strip reaches the cells easily
    - Thinner holder halves (9 mm sockets, 84 cm3 each instead of 116)
    - Copper pieces are one straight bar per row of cells: every cell fully
    covered, 8 mm punch hole marked over each cell on all templates,
    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
    [bms_cradle.stl, cellholder.scad, holder_bottom.stl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]
2026-10-06 Vertical stand for the ANT 24S BMS instead of the flat cradle
    - BMS (125 x 90 x 16, ANT 24ZHE6-24S-220A) stands on its long edge
    parallel to the divider, behind the screw post: ~45 mm of deck length
    - Connector end held by a low channel and face fins (connectors free),
    narrow end by a U clamp with a zip tie looped under the narrow section
    - Open base frame with braces and a notch for the screw post, 18 cm3,
    prints without supports
    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
    [bms_cradle.stl, bms_stand.stl, cellholder.scad]
2026-10-06 Integrate the BMS dock into the top holder half
    - The top half grows a flat arm over the divider with a slot the BMS
    (ANT 24ZHE6-24S-220A, standing on its long edge) drops into; slot is
    open at the connector end and closed by a bar at the narrow end
    - Notches let the B-/B+ tongues fold down, tie hole pairs for the lead
    strain relief and for two straps over the BMS top edge
    - Prints flat with the half (no supports); the split part holder_top_a
    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
    [bms_stand.stl, cellholder.scad, holder_bottom_b.stl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]
2026-10-06 README: what to print for a 256 mm bed and print order
    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
2026-10-06 Split parts lock through shared key-cell sockets, offset seams
    - Print split now runs through one key cell per row: each key socket is
    cut across its centre, halves alternate between part a and b, so the
    pushed-in key cells act as dowels and lock the parts together
    - Top half is split one cell column further than the bottom half so
    the two seams never line up
    - All split parts fit a 256 x 256 bed (largest holder_top_a 214 x 141)
    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
    [cellholder.scad, holder_bottom_a.stl, holder_bottom_b.stl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]
2026-10-07 Add a cell fit test strip (21.1-21.6 mm holes)
    - New part bore_test: one row of 6 sockets built like the holder (same
    lip, depth, pitch and circle resolution), hole size raised next to each
    - Exported to stl/bore_test.stl and added to export.sh
    - README: print the strip first, pick the snug size, set cell_bore/BORE_D
    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
    [bore_test.stl, cellholder.scad]
2026-10-07 Set cell bore to 21.2 mm (picked with the fit test strip)
    - cell_bore / BORE_D 21.6 -> 21.2 mm: cells press in firmly by hand,
    wall between neighbouring cells grows from 0.6 to 1.0 mm
    - All holder STLs re-exported, README bore note updated
    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
    [bore_test.stl, cellholder.scad, holder_bottom.stl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]
2026-10-08 Cell layout: 4-in-a-line checkerboard
    - Every 4p group is 4 cells in a straight line along a row; rows read
    4 neg / 4 pos / 4 neg and alternate downwards (checkerboard of blocks)
    - Series path runs up/down between rows (7 cell contacts per joint);
    only the four block-to-block moves are end-to-end 8-cell strips
    - B- and B+ still at the divider end; holder geometry unchanged
    - Copper templates, cut list, roll plan, diagrams and README updated
    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
    [layout_data.scad]
2026-10-08 Cell layout: no end-to-end joints, no double copper
    - 14 of 20 groups are still straight lines of 4. Consecutive groups are
    never end to end in one row any more: every series joint is between
    neighbouring rows with 3-7 cell contacts (narrowest copper bridge
    ~36 mm, was ~14 mm on the four end-to-end strips).
    - Top lane rows 1-2 and middle lane rows 3-4 use a brick pattern
    (lines alternate rows, shifted 1.5-2.5 cells); the far end and the
    divider end use six short-row shapes; G18-G20 stay stacked lines.
    - B-/B+ unchanged (G1 row 1, G20 row 7, divider end); holder STLs
    unchanged.
    - Docs, copper templates, roll plan (~1.4 m), renders and README
    regenerated; largest neighbouring-pie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
    [layout_data.scad]
2026-10-08 Copper roll plan: nest real outlines, fits a 1 m roll (~0.94 m)
    - roll_plan now packs the real piece outlines on a 0.5 mm raster
    (FFT overlap test, 4 rotations, either side up) instead of bounding
    boxes, so the step shapes interlock.
    - Per face, the biggest set of pieces that fits across the roll is kept
    as one band exactly as on the pack (busbar gap = cut line).
    - Best of a fixed set of piece orders; checks that every piece is on the
    roll and cut lines are >= KERF apart on the true outlines.
    - 1366 mm -> 944 mm of 100 mm roll. README updated.
    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
2026-10-09 Copper as straight strips across the roll (98 cm), no nesting
    - New layout: groups are lines of 4 or 2+2 diamonds, so two
    consecutive groups (= one copper piece) are two rows of 4 cells,
    97 x 36 mm - it fits across the 100 mm roll. Found with a CP-SAT
    search minimising strip length with every joint >= 3 contacts
    (narrowest copper bridge ~36 mm, still no double copper).
    - Roll plan is now straight strips cut across the roll: B-/B+ side by
    side (124 mm), 11 x 36 mm strips (A x7, B x4), 8 x 55 mm strips.
    980 mm total. Replaces the outline nesting (and its numpy/raster
    code); generator is back to under a second.
    - Roll plan SVG shows the strip cut lines and widths.
    - README layout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
    [layout_data.scad]
2026-10-09 Cell layout: slanted bands + 3-row blocks (from the reference build)
    - Rows R0-R3: every group is a diagonal line of 4 (one cell per row);
    two diagonals side by side = one copper piece, the same slanted band
    everywhere (7 contacts). G1 (B-) at the divider corner, G2-G11 away
    from the divider.
    - Rows R4-R6: G12-G20 come back in 3-row diagonal groups (5-7
    contacts); copper pieces are 3-row blocks. G20 (B+) next to the chase.
    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
    [layout_data.scad]
2026-10-09 Match the reference build's polarity: B- next to the chase, B+ at the band corner
    - Series order reversed (same copper pieces): G1 (B-) is the 3-row
    block corner next to the wire chase, G2-G9 run along rows R4-R6,
    G10-G19 are the diagonals back, G20 (B+) the band corner.
    - Lead tongues keep their positions (only the labels swap), so the
    holder and dock STLs are unchanged.
    - README layout table, roll plan and tie-slot note updated.
    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
    [layout_data.scad]
2026-10-13 Copper: cell-outline pieces + A4 cutting guide, fits the 1 m roll (902 mm)
    - COPPER_STYLE = "outline": every piece is trimmed to a ring round each
    cell (RING_R 10 mm) plus 14 mm bridges between neighbouring cells,
    inside the full piece so all gaps / window clearances still hold.
    Narrowest joint ~63 mm. "full" keeps the old full-area pieces.
    - Roll plan: true-outline nesting (0.5 mm raster, FFT overlap test,
    30 deg rotations, either side up, best of NEST_TRIES orders), 1 mm
    between cut lines; 902 mm of 100 mm roll. Result cached in
    generator/roll_nest.json (keyed on the piece outlines).
    - docs/copper_cutting_guide.pdf: black-and-white A4 landscape, 1:1.
    Page 1 how-to, print chec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
2026-10-23 Copper press: press on the pack with a stencil + fake cells
    Replaces the off-pack die/punch. The holder itself is now the die:
    - copper_press_stencil_a / _b: 6 mm guide grid with a hole over every
    cell slot. Its skirt drops over the holder's side walls, far end and
    the two divider-end corners, so each hole sits exactly over a welding
    window. Split along the holder's own zig-zag seam (split_a) so both
    halves are single bodies and fit a 256 bed; each locates by itself.
    Same grid from above and below, so it fits both faces.
    - copper_press_fake_cell: plunger the size of a cell end; slides in the
    stencil hole and pushes the copper through the 17 mm window onto the
    cell. Collar = dep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
